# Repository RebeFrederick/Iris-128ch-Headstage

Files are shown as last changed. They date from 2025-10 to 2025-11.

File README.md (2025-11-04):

# Iris-128

Open-source 128-channel headstages for neural stimulation and recording.

*The publication of this work can be found at DOI 10.1088/1741-2552/ae1876. The raw data files corresponding to the publication can be found at https://doi.org/10.17605/OSF.IO/XS2PU.*

> [!NOTE]
> Detail documentation and user guides can be found at https://docs.openic.org/iris-128.

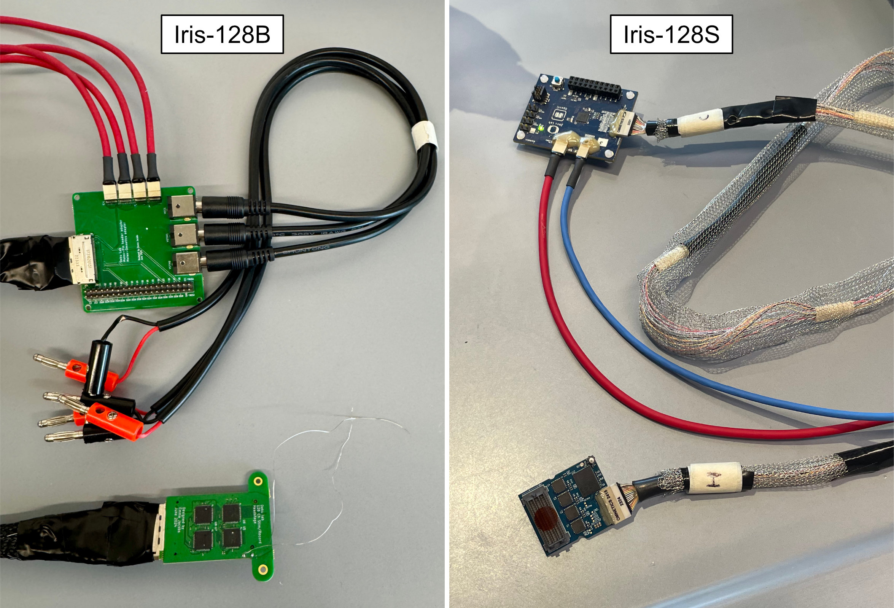
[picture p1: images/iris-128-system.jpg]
Iris-128


| Type | Description |
| :--: | :--- |
| [Iris-128B](iris-128b/README.md)  | Fully bidirectional headstage with recording or stimulation across all 128 electrode channels. |
| [Iris-128S](iris-128s/README.md) | Selective stimulation headstage with recording from 128 channels and stimulation on 16 simultaneous channels out of 32 available stimulation channels. |
| [Thin-film electrode](thin-film/README.md) | 128 channel surface array used as a test platform for the headstages. |

## File Structure

| Folder  | Description |
| :-----: | :--- |
| iris-128b | Project, design, and fabrication files related to Iris-128B Neural Interface System. |
| iris-128s | Project, design, and fabrication files related to Iris-128S Neural Interface System. |
| thin-film | Design files related to the microelectrode test platform. |
| images | image files used in README and description files. |

## EDA Tools used in the Development

| EDA Tool | Version | Usage |
| :---: | :-----: | :--- |
| KiCad | 8.0.5 | Design of PCBs. |
| KiCad | 9.0.3 | Design of PCBs. |
| STM32CubeIDE | 1.16.0  | Design of firmware for MCU. |

## Developers

* Deku Lab, University of Oregon, Eugene, OR
* OpenIC, Eagan, MN

## License

Copyright Manuel Monge, Emma Jacobs 2025.

This source describes Open Hardware and is licensed under CERN-OHL-P v2.

You may redistribute and modify this source and make products using it under the terms of the CERN-OHL-P v2 ([https:/cern.ch/cern-ohl](https:/cern.ch/cern-ohl)). This source is distributed WITHOUT ANY EXPRESS OR IMPLIED WARRANTY, INCLUDING OF MERCHANTABILITY, SATISFACTORY QUALITY AND FITNESS FOR A PARTICULAR PURPOSE. Please see the CERN-OHL-P v2 for applicable conditions.

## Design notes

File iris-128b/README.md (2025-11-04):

# Iris-128B
> [!NOTE]
> Detail documentation and user guides can be found at https://docs.openic.org/iris-128/iris-128b.

<br>

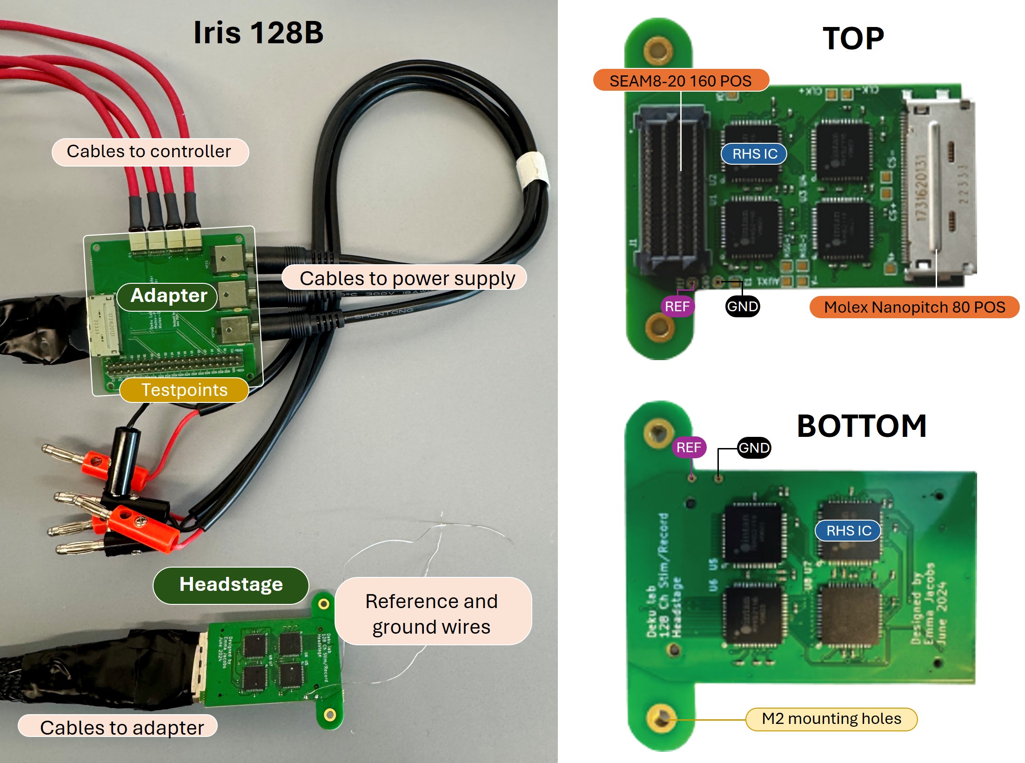
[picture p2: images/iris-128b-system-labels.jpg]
Iris-128


*Fig. 1. Iris-128B Neural Interface.*

## Description

### Overview

A **128-channel neural interface capable of stimulation and recording**.

This project develops a system that can stimulate and record from 128 channels using commercially available ICs and integrates into existing commercially available controllers (Intan RHS system). This can be used for small animal, anesthetized electrophysiology, non-human primates, or could be applied to clinical, intraoperative human use cases.

### Iris 128B Architecture

*The Iris 128B system consists of 2 boards: the headstage and the adapter.*

* The **headstage** is a small electronic system placed on top of or near the electrophysiological signals being recorded.
* It uses **commercially available off-the-shelf components**.
* The **adapter board** receives signals from the headstage (through the 80 pin nanopitch Molex connector and cable) and breaks them out into cables that interface with the **Intan Rec/Stim Controller**.

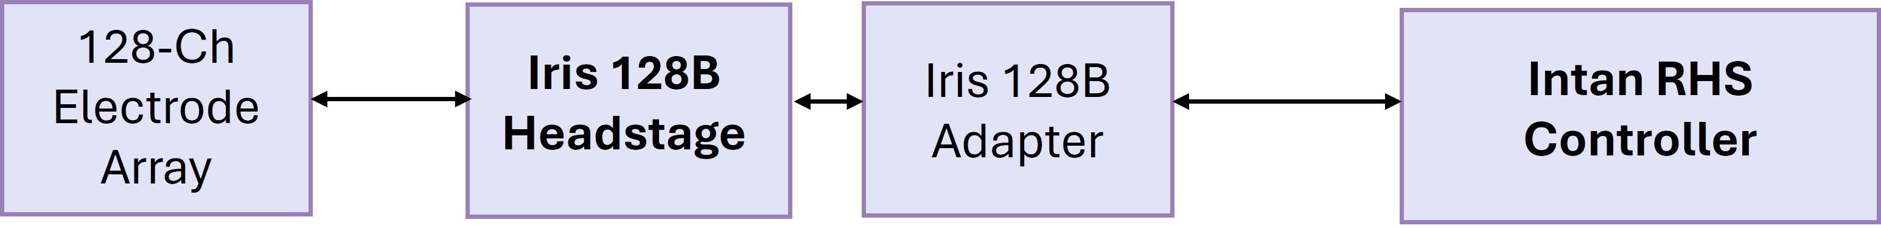
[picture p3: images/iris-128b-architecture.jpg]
Iris-128


*Fig. 2. System architecture.*

<br>

## Specifications

* Recording and stimulation from all 128 channels.
* Compatible with Intan Recording Controller and Intan Stim/Record Controller.
* *SEAM8 Samtec* connector for interfacing with 128-ch electrode array and compatible with *BlackRock Cereplex E headstages*.
* The *headstage* has a size of 27 x 44 mm$^2$.
* *Molex Nanopitch 76-POS* connector to interface with *Adapter* board through a single cable.
* *Adapter* board draws power from power supply.
* The *adapter* has a size of 57 x 58 mm$^2$.

<br>

## File Structure

### Top Folders: /iris-128b

| Folder  | Subfolders | Description |
| :-----: | :--- | :--- |
| pcb | iris-128b <br> iris-128b-adapter <br> libraries | Project, design, and fabrication files related to Iris-128B headstage PCB fabrication and assembly. <br> Project, design, and fabrication files related to Iris-128B adapter PCB fabrication and assembly. <br> Ki-Cad libraries and common files used in PCBs |

<br>

### PCB Folders: /iris-128b/pcb/

| Folder  | Subfolders | Description |
| :-----: | :--- | :--- |
| . / |  | Project and design files related to Iris128B. |
| manufacturing |  gerber <br> assembly <br> bom | Gerber files for fabrication of `Iris-PCB`. <br> Assembly files for `Iris-PCB`. <br> Bill of Materials for `Iris-PCB`. |

<br>

## File Types

| File | Folder | Description |
| :--- | :----- | :--- |
| README.md | iris-128x | Description of Iris-128X system. |
| kicad-files | iris-128x / pcb / | Ki-Cad project and design files. |
| gerber-files | iris-128x / pcb / manufacturing / gerber | Gerber files. |
| iris-128x-all-pos.csv | iris-128x / pcb / manufacturing / assembly | Assembly files in `csv` format.|
| iris-128x_bom.csv | iris-128x / pcb / manufacturing / bom | Bill of materials in `csv` format. |
| symbol-libraries | iris-128x / pcb / libraries | Ki-Cad symbol libraries used in PCBs. |
| footprint-libraries | iris-128x / pcb / libraries | Ki-Cad footprint libraries used in PCBs. |

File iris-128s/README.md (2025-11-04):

# Iris-128S
> [!NOTE]
> Detail documentation and user guides can be found at https://docs.openic.org/iris-128/iris-128s.

<br>

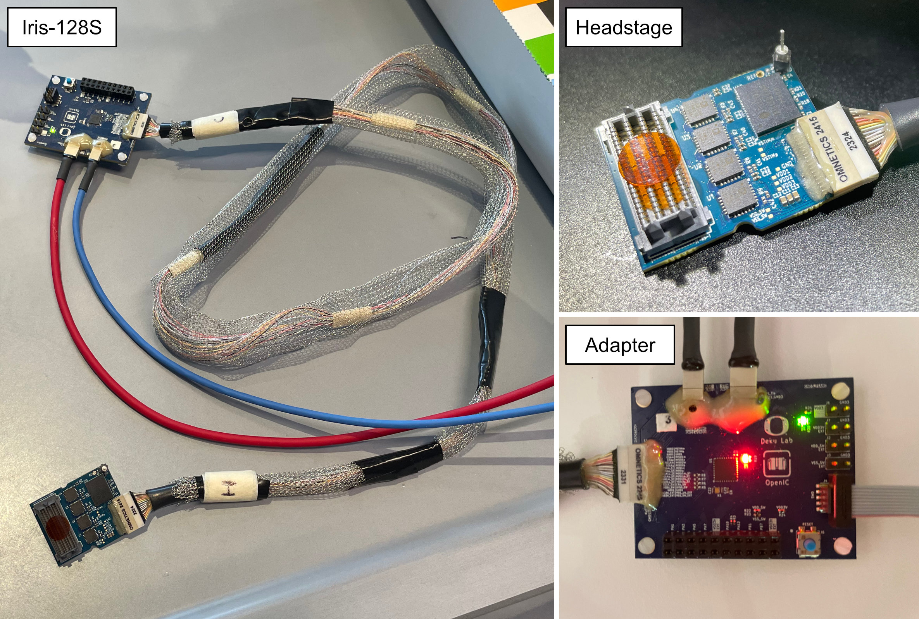
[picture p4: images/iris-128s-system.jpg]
Iris-128S System

<p style="text-align:center"><i><b>Figure 1.</b> Iris-128S Neural Interface.</i></p>

<br>

## Description

The Iris-128S neural interface consists of 2 boards: the *headstage* and the *adapter*. The *headstage* is a small electronic board that is normally placed on top of or nearby the animal model being studied. It has been designed to be as small as possible while using standard, commercially available off-the-shelf components. The *adapter* is a small electronic board which has been designed to interface with the Intan Recording Controller, the Intan Rec/Stim Controller, and a programmer/computer to program the switches in the *headstage* via a MCU.

The architecture and schematic of Iris-128S are shown in the figures below.

```mermaid
graph LR
    c0["128-Ch
        Electrode
        Array"]
    c1["`**Headstage**`"]
    c2["`**Adapter**`"]
    c3["Intan Rec
        Controller"]
    c4["Intan Rec/Stim
        Controller"]
    c5["Programmer"]
    c0 <--> c1
    c1 <----> c2
    c2 <--> c3
    c2 <--> c4
    c2 <--> c5
```
<p style="text-align:center"><i><b>Figure 2.</b> System Architecture of Iris-128S.</i></p>

<br>

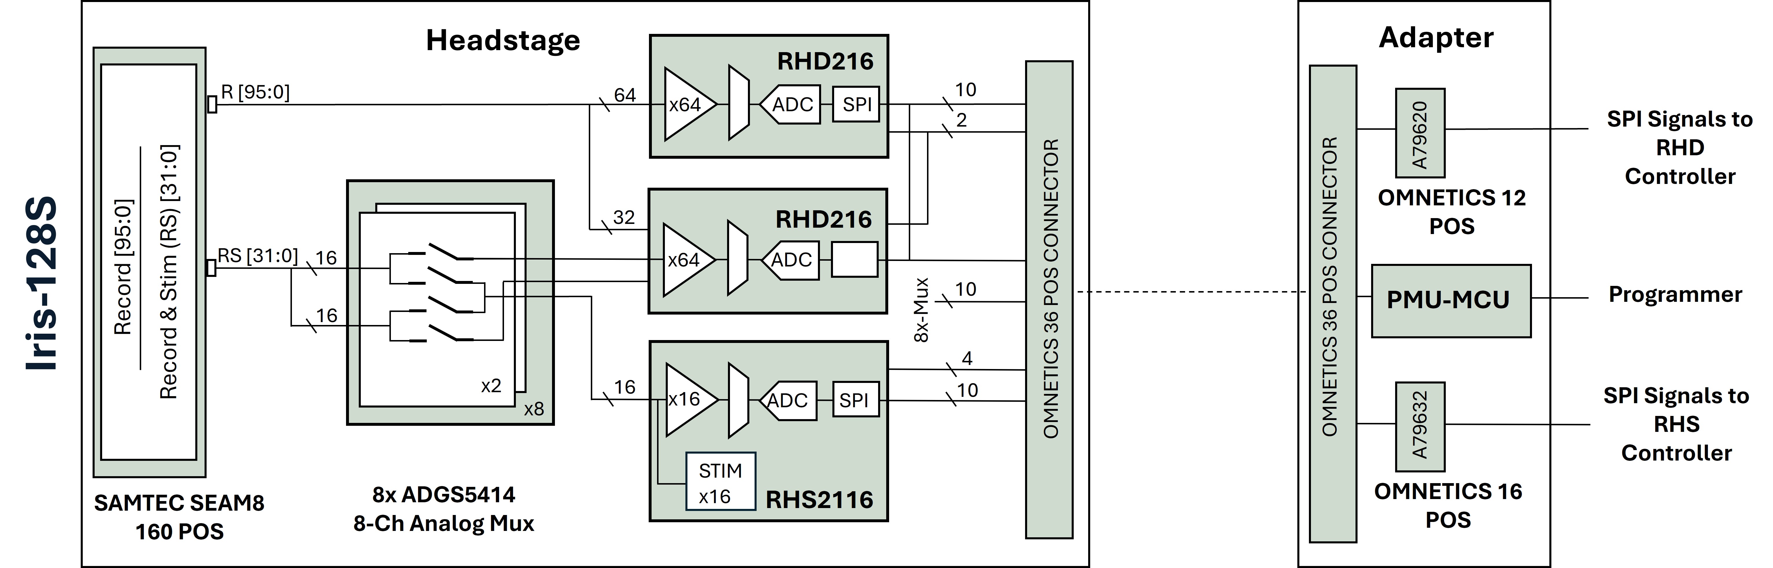
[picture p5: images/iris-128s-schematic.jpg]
Iris-128S System

<p style="text-align:center"><i><b>Figure 3.</b> Schematic of Iris-128S.</i></p>

<br>

## Specifications

* Recording from all 128 channels.
* Stimulation from 32 designated channels, where up to 16 of them can be selected for simultaneous stimulation.
* Compatible with Intan Recording Controller and Intan Stim/Record Controller.
* *SEAM8 Samtec* connector for interfacing with 128-ch electrode array and compatible with *BlackRock Cereplex E headstages*.
* The *headstage* has a size of 30.2 x 25.5 mm$^2$.
* *Omnetics 36-POS* connector to interface with *Adapter* board through a single cable.
* *Adapter* board draws power directly from the Intan Recording Controller to power itself and the *headstage*.
* On-board power management unit (PMU) in the *Adapter* board generates the required supplies for the MCU and *ADGS5414* switches.
* Programmer in the *Adapter* board is only needed to update the firmware in the MCU, i.e., change the state of the *ADGS5414* switches. After MCU is programmed, only the Intan controlleres are needed.
* The *adapter* has a size of 50 x 40 mm$^2$.

<br>

## File Structure

### Top Folders: /iris-128s

| Folder  | Subfolders | Description |
| :-----: | :--- | :--- |
| pcb | iris-128s <br> iris-128s-adapter <br> libraries <br> datasheets | Project, design, and fabrication files related to Iris-128S headstage PCB fabrication and assembly. <br> Project, design, and fabrication files related to Iris-128S adapter PCB fabrication and assembly. <br> Ki-Cad libraries and common files used in PCBs <br> Datasheets of components used in PCBs. |
| mcu | controller | Project and firmware files related to MCU programming. |

<br>

### PCB Folders: /iris-128s/pcb/`Iris-PCB`

| Folder  | Subfolders | Description |
| :-----: | :--- | :--- |
| . / |  | Project and design files related to `Iris-PCB`. |
| manufacturing |  gerber <br> assembly <br> bom | Gerber files for fabrication of `Iris-PCB`. <br> Assembly files for `Iris-PCB`. <br> Bill of Materials for `Iris-PCB`. |

<br>

### MCU Folders: /iris-128s/mcu

| Folder  | Subfolders | Description |
| :-----: | :--- | :--- |
| controller | Core / Inc <br> Core / Src <br> Core / Startup <br> Debug <br> Drivers | `C` library files. <br> `C` source files. <br> Assembly startup file. <br> Debug-related files. <br> Driver files for target MCU. |

<br>

## File Types

| File | Folder | Description |
| :--- | :----- | :--- |
| README.md | iris-128x | Description of Iris-128X system. |
| pcb-fab-specs.md | iris-128x / pcb | Specifications for the fabricatin of `Iris-PCB`.
| kicad-files | iris-128x / pcb / `Iris-PCB` | Ki-Cad project and design files. |
| iris-128x-schematic.pdf | iris-128x / pcb / `Iris-PCB` | PDF of PCB schematic. |
| gerber-files | iris-128x / pcb / `Iris-PCB` / manufacturing / gerber | Gerber files. |
| iris-128x-all-pos.csv | iris-128x / pcb / `Iris-PCB` / manufacturing / assembly | Assembly files in `csv` format. |
| iris-128x_bom.csv | iris-128x / pcb / `Iris-PCB` / manufacturing / bom | Bill of materials in `csv` format. |
| datasheet-files.pdf | iris-128x / pcb / datasheets | PDFs of the datasheets of all components used in PCBs. |
| symbol-libraries | iris-128x / pcb / libraries | Ki-Cad symbol libraries used in PCBs. |
| footprint-libraries | iris-128x / pcb / libraries | Ki-Cad footprint libraries used in PCBs. |
| main.c | iris-128s / mcu / controller / Core / Src | Main `C` file running on MCU. |
| c-files | iris-128s / mcu / controller / Core | `C` files related to MCU firmware. |
| c-files | iris-128s / mcu / controller / Debug | `C` files related to MCU debugging. |
| c-files | iris-128s / mcu / controller / Drivers | `C` file related to MCU drivers. |
| .*project | iris-128s / mcu / controller | STM32CubeIDE project-related files. |
| *.launch | iris-128s / mcu / controller | STM32CubeIDE debug-related files. |
| *.ioc | iris-128s / mcu / controller | STM32CubeIDE MCU system configuration file. |
| *.id | iris-128s / mcu / controller | STM32CubeIDE MCU memory configuration file. |

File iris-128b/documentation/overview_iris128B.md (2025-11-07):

# Iris-128B

Iris-128

*Fig. 1. Iris-128B Neural Interface.*

The left labels the cables and components needed for the system, in addition to the Intan RHS controller and electrodes. Fig. 1 shows the front of Iris 128B with a SEARAY 160 pin connector, four RHS2000 ICs, an 80-pin Molex connector, pinouts, decoupling capacitors, and terminating resistors. Mounting holes are M2. The back of Iris 128B with four RHS2000 ICs.

## Description

### Components

The descriptions of each part of the system can be found below, along with a quick start guide.

| Component | Page |
| :-----: | :----- |
| Headstage | Headstage|
| Adapter | Adapter|
| Quick start guide | Quick start guide|

### Overview

A 128-channel neural interface capable of stimulation and recording.

This project develops a system that can stimulate and record from 128 channels using commercially available ICs and integrates into existing commercially available controllers (Intan RHS system). This can be used for small animal, anesthetized electrophysiology, non-human primates, or could be applied to clinical, intraoperative human use cases.

### Iris 128B Architecture

*The Iris 128B system consists of 2 boards: the headstage and the adapter.*

* The headstage is a small electronic system placed on top of or near the electrophysiological signals being recorded.
* It uses commercially available off-the-shelf components.
* The adapter board receives signals from the headstage (through the 80 pin nanopitch Molex connector and cable) and breaks them out into cables that interface with the **Intan Rec/Stim Controller**.

Iris-128

*Fig. 2. System architecture.*

<br>

## Specifications

* Recording and stimulation from all 128 channels.
* Compatible with Intan Recording Controller and Intan Stim/Record Controller.
* *SEAM8 Samtec* connector for interfacing with 128-ch electrode array and compatible with *BlackRock Cereplex E headstages*.
* The *headstage* has a size of 27 x 44 mm$^2$.
* *Molex Nanopitch 76-POS* connector to interface with *Adapter* board through a single cable.
* *Adapter* board draws power from power supply.
* The *adapter* has a size of 57 x 58 mm$^2$.

<br>

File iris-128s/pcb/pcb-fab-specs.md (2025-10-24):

# Iris-128S PCB Specifications

The table below shows the specifications for the Iris-128S PCBs.

| Specification | Headstage | Adapter |
| :---: | :---: | :---: |
| Min. Trace Width/Space | 3 mil / 3 mil  | 5 mil / 5 mil |
| # Layers | 8 | 4 |
| $\mu$Via (Hole/Diameter) | 6 mil / 12 mil | None |
| Thru-Hole Via (Hole/Diameter) | 8 mil / 14 mil | 10 mil / 20 mil |
| Board Thickness | 1 mm | 1.6 mm |
| Surface Finish | ENIG | ENIG |
| Copper Weight | 1 oz | 1 oz |
| Dielectric | Standard FR4 | Standard FR4 |

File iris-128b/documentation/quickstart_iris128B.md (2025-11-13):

# Iris-128B Quickstart Guide
*Open-Source 128-Channel Headstage for Neural Recording and Stimulation*  
*(Based on Jacobs et al., 2025 – “Iris 128x: Open-Source 128-Channel Headstages for Neural Stimulation and Recording”)*  

---

## 1. System Overview

The Iris-128B system provides 128-channel, fully bidirectional recording and stimulation capability using eight Intan RHS2116 integrated amplifier/stimulator chips.  
It interfaces with thin-film microelectrode arrays through a Samtec SEAF8-20-1-S-08-2-RA connector and communicates with an Intan RHS Controller via low-voltage differential signaling (LVDS) through a Molex 80-pin nanopitch cable and an adapter board.

---

## 2. Power Supply Requirements

Use a bench DC power supply such as the HP E3631A Triple Output DC Power Supply (HP Inc., Palo Alto, CA).  

| Rail | Voltage | Current Limit | Description |
|---|---|---|---|
| **Vstim +** | +7 V | 100 mA | Positive stimulation rail |
| **Vstim –** | –7 V | 100 mA | Negative stimulation rail |
| **VCC** | +3.3 V | 100 mA | Digital logic & analog power |

> **Tip:** Keep each supply current-limited to 100 mA to protect the headstage.

iris-128

*Fig. 1. Wiring diagram containing power supplies, intan controller, adapter board, and cable to headstage.*

---

## 3. Hardware Components

- **Headstage (Iris-128B)**  
  - 8 × Intan RHS2116 ICs (recording + stimulation)  
  - Samtec SEAF8 connector (160-pin) for thin-film MEA  
  - Molex 80-pin nanopitch output to adapter  
  - ±3.3 – 7 V supply range  

- **Adapter Board**  
  - Passive signal routing (no active components)  
  - 4 × Omnetics A79633 connectors to Intan RHS ports A–D  
  - 3 × barrel jacks for ±Vstim and VCC  

iris-128

*Fig. 2. Components and connections of headstage and adapter board.*

---

## 4. Hardware Setup

### Step 1 — Prepare for Surgery

1. Secure the animal in a stereotaxic frame.  
2. Mount the 3D-printed headstage holder onto the stereotax.  
3. Seat the thin-film electrode connector into the holder.  
4. Plug the Iris-128B headstage into the thin-film connector.  
5. Fasten the headstage to the holder via mounting holes.

iris-128

*Fig. 3. (A) Headstage with thinfilm attached to stereotax in 3d printed fixture. (B) Headstage and thinfilm.*

---

### Step 2 — Connect to Adapter

1. Connect the Molex 80-pin cable between headstage and adapter.  
2. Route this cable outside the Faraday cage.  
3. Plug in the 4 RHS interface cables (red Omnetics):  
   - **S1 → Port A** (shared CLK and CS)  
   - **S2 → Port B**  
   - **S3 → Port C**  
   - **S4 → Port D**

---

### Step 3 — Ground and Reference

- Connect REF and GND pads using platinum wires soldered into the through-holes on the headstage.  
- Keep REF and GND unshorted during normal operation.  
- Optionally, these may be tied together or implemented on the thin-film array.  
- Ensure the entire setup (animal, cage, supplies) shares a common ground.

---

## 5. Software Setup

1. Install Intan RHS Recording Controller Software (see [Intan User Guide](https://intantech.com)).  
2. Connect the RHS Controller to the computer via USB.    

---

## 6. Power-Up Sequence

1. Confirm the Intan controller and power supplies are connected to the chassis ground on the controller (green plug on back of controller) and the grounds on the power supply are all connected to each other as well.  
2. Set voltages on the HP E3631A:  
   - +7 V, –7 V, +3.3 V rails  
   - 100 mA current limits  
3. Plug barrel jacks into Vstim± and VCC inputs on the adapter.  
4. Turn on the power supply. 
5. Turn on the Intan Controller.
6. Launch the software — channels from Ports A–D should automatically appear.  
7. Adjust sampling rate and channel naming as needed.

iris-128

*Fig. 4. Software launch with 4 connected ports (total 128 channels).*

---

## 7. Bench & Animal Setup Checklist

| Stage | Procedure |
|---|---|
| **Bench Validation** | Connect planar 128-ch polyimide MEA → verify impedance in PBS (~295 kΩ @ 1 kHz). |
| **Grounding** | Attach platinum wires for REF and GND to headstage pads. |
| **Recording** | Launch Intan software → set sampling rate 30 kSa/s → confirm signal. |
| **In Vivo Setup** | Craniotomy → insert MEA into cortex → connect headstage. |
| **Validation** | Observe LFPs (0.5–100 Hz) and single-unit spikes (~250–500 µVpp). |

---

## 8. Performance Summary

| Metric | Iris 128B | Comparison (Intan 32 ch) |
|---|---|---|
| Noise (Vrms) | 3.09 µV | 2.4 µV |
| Weight | 9.6 g | 1.4 g |
| Volume | 1188 mm³ | 576 mm³ |
| Channels | 128 stim / 128 record | 32 stim / 32 record |
| Frequency Response | 0.5 Hz – 5 kHz (flat midband gain) | Similar |
| Impedance (1 kHz, Pt site) | ~2.9 × 10⁵ Ω | 2.4 × 10⁵ Ω |
| Supply | ±7 V & 3.3 V | 3.3 V (single) |

---

## 9. Stimulation Parameters

- **Chip:** Intan RHS2116 (D5716)  
- **Current Range:** 2.55 µA – 255 µA  
- **Step Size:** 10 nA – 10 µA  
- **Supply Range:** ±3.3 – 10.7 V (max combined 14 V)  
- **Sampling Rates:** 1 – 30 kS/s  
- **Test Waveform:** Biphasic cathodic-first 4 µA, 500 µs pulses, 100 Hz (0.1 mC/cm² charge density)

---

## 10. Additional Notes

- The Molex #205058-1002 cable assembly is discontinued; contact  
  **fdeku@uoregon.edu** or **manuel@openic.org** for updated options.  
- The design files, schematics, and BOMs are open-source on GitHub (OpenIC / U Oregon).  
- The Iris 128B and 128S share identical PCB stack-up and fabrication parameters:  
  – 8-layer (3 mil trace / space, ENIG finish, 1 oz Cu).  
- Designed in KiCad*, verified by micro-CT imaging and in vivo electrophysiology recordings.  
- For portable or wireless operation, future iterations aim to reduce weight < 5 g and integrate on-board power management.

---

## 11. Reference Setup Recipe

1. Power on HP E3631A (±7 V & 3.3 V outputs).  
2. Connect thin-film → headstage → adapter → Intan Controller.  
3. Verify REF/GND connections (platinum wire → bone screws).  
4. Enable power and confirm communication in Intan software.  
5. Begin recording and stimulation tests.

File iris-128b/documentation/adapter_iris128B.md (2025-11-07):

# Adapter

iris-128

*Fig. 1. Adapter connections.*

*The Iris 128B system consists of 2 boards: the headstage and the adapter.*

* The adapter board receives signals from the headstage (through the 80 pin nanopitch Molex connector and cable) and breaks them out into cables that interface with the Intan Rec/Stim Controller.

This is a board with no active components on it. It's purpose is simply to route the connections from the Iris-128B headstage to the power supply, and the four ports on the Intan RHS controller. It also has some header pins intended for testing the SPI connections.

---

### Specifications

This is a 4 layer board that only routes digital signals. It takes the signals from the headstages and breaks them out into the appropriate connector for the RHS intan controller (interfacing with PZN 18 pin omnetics cables).

iris-128

*Fig. 2. Omnetics output from adapter board. This is repeated 4 times. Each connector routes two chips into the ports on each controller.*

#### Table 1. PCB Specifications

| PCB Specification | Value |
| --- | --- |
| Size | 27 × 44 mm² |
| Trace Width / Space | 3 mil / 3 mil |
| Layers | 8 |
| Thru-Hole Via (Hole / Diameter) | 8 mil / 14 mil  |
| Microvia (Hole / Diameter) | 6 mil / 12 mil  |
| Thickness | 0.039 in (1 mm) |
| Surface Finish | ENIG |
| Copper Weight | 1 oz |

#### Table 2. Adapter components

| Component | Part | Manufacturer | Description |
| --- | --- | --- | --- |
| J1 | SEAM8-20-S02.0-S-08-3 | Samtec | 160-pin connector to electrode sites. |
| S1-S4 | Omnetics A79633 PZN-16-AA| Intan | Intan |Connector for RHS2000 interface (chip side) to the Intan controller |  
| VSTIM-, VSTIM+, VCC | CP-063AH-ND  Pwr Jack| Molex | Barrel jack inputs for the power supplies. |

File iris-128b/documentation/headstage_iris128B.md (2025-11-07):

# Headstage

Iris-128
*Fig. 1. Schematic of Iris 128B.*

*The Iris 128B system consists of 2 boards: the headstage and the adapter.*

* The headstage is a small electronic system placed on top of or near the electrophysiological signals being recorded.
* It uses commercially available off-the-shelf components.

### Fabrication Notes

The cable used to connect the headstage to the adapter board is Molex 8X STR NPIO/ 8X STR NPIO 2PC LATCH 34A, #205058-1002. This cable is no longer manufactured. However, the connector is still available. We are working on alternatives - and a smaller version of these headstages. Feel free to contact us (fdeku@uoregon.edu or manuel@openic.org) if you would like to use this design and want to discuss alternative options. 

If you are able to use the Molex nanopitch cables, please note:

* In this design, pins *Chip 5 – MOSI+* and *Chip 5 – MOSI–* connect to unused pins on the cable (A20 and A21). To address this we modified the cable by adding wires to it after it was ordered.

#### Headstage Cost Breakdown

- 8 × $392 — RHS2116 chips  
- 1 × $24 — SEAM8-20-S02.0-S-08-3 connector  
- 1 × $67 — NPIO / 8X STR NPIO 2PC LATCH 34A cable **_(DISCONTINUED AS OF AUG. 2025)_**  
- 1 × $11 — CONN NANO-PITCH I/O RCPT 80P RA connector  
- $125 — 1 headstage printed circuit board  
- $60 — 1 adapter printed circuit board  
- 4 × $265 — RHS interface cables  

----

#### **Estimated Total Costs**
- **≈ $3,356** — Headstage  
- **≈ $1,325** — Cabling

### Components

| Component | Part | Manufacturer | Description |
| --- | --- | --- | --- |
| J1 | SEAM8-20-S02.0-S-08-3 | Samtec | 160-pin connector to electrode sites. |
| U1–U8 | RHS2116 | Intan | Stimulation & recording chip.  |
| J2 | CONN NANO-PITCH I/O RCPT 80P RA, #1731620131 | Molex | 80-pin connector that routes the digital signals from the headstage to the adapter board.  |

## Specifications

### Electrode128

*This is the output/input that interfaces with the electrophysiological signals.*

We are currently using the SEAM8 Samtec connector for interfacing with a 128-ch electrode array.
The footprint on the headstage is shown below.

The left and right two rows are dedicated for GND and REF connectors.
The remaining 16×8 are for connecting to the 128 electrodes. All the GND for the chips, power supplies, and thin-film are shared.

This is the same footprint/connector used with BlackRock Cereplex E headstages, maintaining compatibility with interchangeable thin-film interfaces.

Iris-128

*Fig. 2. Footprint of SEAM 160 (8x20) pin connector. Outer two rows are reserved for reference and gnd. The 3.3V and LED are unconnected. The locations of these gnd and reference pins are meant to match the Cereplex E headstages. We have used thin-films interchangeably between the two systems so we have preserved that footprint in this version of the headstage. The footprint is labeled C#, indicating the chip it routes to, and E# indicating the electrode.*

### Chip1 through Chip8

These are RHS2116 chips (QFN package) from Intan Technologies.
There are 8 total chips (16 electrodes each) communicating with the controller via SPI (Serial Peripheral Interface). 

Iris-128

*Fig. 2. Footprint of RHS2116 on Iris128B with broadly labeled pins. See the Intan RHS2116 datasheet for specific details. *

The reference and ground pins can be shorted or disconnected using the pads shown below.

Iris-128

*Fig. 3. Footprint location of pads to short ref and gnd. Also seen here are the plated through holes on the left where gnd and ref wires can be soldered.*

Digital (SPI) communication lines to each of the 8 chips:

* Chip Select (CS)
* Serial Clock (SCLK)
* Serial Data Input (MOSI)
* Serial Data Output (MISO)

Because **LVDS (Low-Voltage Differential Signaling)** is used to decrease noise sensitivity, each line type has a + and – pair:

* CS+, CS–
* SCLK+, SCLK–
* MOSI+, MOSI–
* MISO+, MISO–

LVDS transmits low-voltage paired differential signals, reducing electromagnetic interference (EMI).

**Power requirements:**

* ±3.3V to ±7V for stimulation
* 3.3V for digital logic and analog power
* ~50 mW consumption (RHS2116, 16 channels recording)

For comparison:

* **RHD2164**: 3.3V single supply, no stimulation, ~75 mW for 64 channels.

Iris-128

*Fig. 4. Footprint of Molex 80 pin connector on Iris128B with broadly labeled pins. Any unlabled pins are digital communication lines to the chips. Not the x for NC pins due to the commericially available cable assembly.*

SPI lines are routed through the adapter board to the Intan RHS controller ports A–D.
SCLK and CS lines are shared between all chips, while data input/output lines are individually connected.

### Layers

#### Table 1. PCB Specifications

| PCB Specification | Value |
| --- | --- |
| Size | 27 × 44 mm² |
| Trace Width / Space | 3 mil / 3 mil |
| Layers | 8 |
| Thru-Hole Via (Hole / Diameter) | 8 mil / 14 mil  |
| Microvia (Hole / Diameter) | 6 mil / 12 mil  |
| Thickness | 0.039 in (1 mm) |
| Surface Finish | ENIG |
| Copper Weight | 1 oz |

Iris-128

#### Table 5. Headstage PCB Stack Up

| Layer | Notes |
| ----- | --- |
| 1 | Minimal local routing + GND plane |
| | *Prepreg* |
| 2 | Supplies + SPI + some electrode signal routing + GND plane |
| | *Core* |
| 3 | GND plane |
| | *Prepreg* |
| 4 | Signal routing + some supply traces + GND plane |
| | *Core* |
| 5 | Signal routing + GND plane |
| | *Prepreg* |
| 6 | Signal routing + GND plane |
| | *Core* |
| 7 | GND plane + SPI routing |
| | *Prepreg* |
| 8 | Minimal local routing + GND plane |

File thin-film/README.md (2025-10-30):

# Thin-film

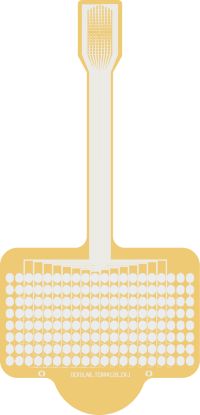
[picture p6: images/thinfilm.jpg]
Thin-film


*Fig. 1. Thinfilm used as test platform for headstages.*

## Description

`THINFILM`.

### Overview

A **Thinfilm**.

This is the design for the 128 microelectrode array fabricated by the Deku lab to test the Iris 128B and S headstages.

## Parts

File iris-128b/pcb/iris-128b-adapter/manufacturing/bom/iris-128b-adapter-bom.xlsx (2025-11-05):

Item # | *Designator | *Qty | Manufacturer | *Mfg Part # | Description / Value | *Package/Footprint | Mounting Type
1 | J1 | 1 | Digikey | WM24876TR-ND - Tape & Reel (TR) | CONN NANO-PITCH I/O RCPT 80P RA | SMD | SMD
2 | C3, C2, C1 | 3 | Mouser | 963-TMK063B7103KP-F | Multilayer Ceramic Capacitors MLCC - SMD/SMT 963-MSAST063SB7103KF RPLCMT PN 25V 0.01uF X7R 0201 10% | SMD | SMD
3 | J2 | 1 | Mouser | 571-7-146256-0 | Headers & Wire Housings 40P HEADER GOLD 15u double row | Thru-hole | Thru-hole
4 | VSTIM-, VSTIM+, VCC | 3 | Digikey | CP-063AH-ND | CONN PWR JACK 2X5.5MM SOLDER | Thru-hole | Thru-hole
5 | S1, S2, S3, S5 | 4 |  |  | POLARIZED NANO CONNECTOR | SMD | SMD
6 | R1, R2, R3, R4, R5, R6 | 6 | Digikey | CRCW0201100RFNED | RES SMD 100 OHM 1% 1/20W 0201 | SMD | SMD

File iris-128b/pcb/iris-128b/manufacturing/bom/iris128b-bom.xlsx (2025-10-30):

Item # | *Designator | *Qty | *Mfg Part # | Description / Value | Vendor Part # | *Package/Footprint | Mounting Type
1 | J1 | 1 | SEAM8-20-S02.0-S-08-3 | CONN HD ARRAY PLUG 0.8MM 8X20POS | Samtec Inc.『 』SEAM8-20-S02.0-S-08-3 | SMD | SMD
2 | C1-C24 | 24 |  | CAP CER 0.1UF 10V X5R 0201 | Digikey『 』3372-0201W104K100LETR-ND | SMD | SMD
3 | U1, U2, U3, U4, U5, U6, U7, U8 | 8 |  | Intan RHS 2000 | Intan | QFN | SMD
4 | R10, R11, R2, R3, R4, R5, R6, R7, R8, R9 | 4 | RC0201FR-07100RL | RES 100 OHM 1% 1/20W 0201 | Digikey『 』311-100MTR-ND | SMD | SMD
5 | LVDS1, LVDS3, LVDS2, LVDS4, LVDS5, LVDS8, LVDS7, LVDS6, R1 | 13 | RMCF0201ZT0R00 | RES 0 OHM JUMPER 1/20W 0201 | Digikey『 』RMCF0201ZT0R00TR-ND | SMD | SMD
6 | C25-32 | 8 | TMK063B7103KP-F | Multilayer Ceramic Capacitors MLCC - SMD/SMT 963-MSAST063SB7103KF RPLCMT PN 25V 0.01uF X7R 0201 10% | Mouser『 』963-TMK063B7103KP-F | SMD | SMD
7 | J2 | 1 | 1731620131 | CONN NANO-PITCH I/O RCPT 80P RA | Digikey『 』WM24876TR-ND - Tape & Reel (TR) | SMD | SMD

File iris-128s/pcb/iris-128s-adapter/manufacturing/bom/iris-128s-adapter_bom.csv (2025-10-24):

Reference | Value | Qty | DNP | MPN | Manufacturer | Description
C1 | 4.7u | 1 |  | KGM05CR51C475MH | Kyocera AVX | Unpolarized capacitor
C2,C9,C11,C16,C18,C19 | 1u | 6 |  | GRM033R61C105ME15D | Murata Electronics | Unpolarized capacitor
C3,C4,C6,C24 | 100n | 4 |  | C0603X5R1C104K030BC | TDK | Unpolarized capacitor
C5 | 10n | 1 |  | GRM033R61C103KA12D | Murata Electronics | Unpolarized capacitor
C7,C12,C13 | 10u | 3 |  | GRM188R61E106KA73D | Murata Electronics | Unpolarized capacitor
C8,C10 | 33n | 2 |  | GRM033R61C333KE84D | Murata Electronics | Unpolarized capacitor
C14,C15,C20,C21 | 2.2u | 4 |  | GRM035R61C225ME01D | Murata Electronics | Unpolarized capacitor
C17 | 1n | 1 |  | GRM033R61E102KA01J | Murata Electronics | Unpolarized capacitor
C22,C23 | 2p | 2 |  | GJM0335C1E2R0WB01D | Murata Electronics | Unpolarized capacitor
D1,D2 | ~ | 2 |  | SDM05U20CSP-7 | Diodes Incorporated
D3 | ~ | 1 |  | CSL1901UW1 | ROHM | LED-RED-0603-ROHM-CSL1901UW1
D4 | ~ | 1 |  | LGQ396 | OSRAM | LED-GREEN-0603-OSRAM-LGQ396
J1,J2,J3,J7 | ~ | 4 |  | TLW-102-06-G-S | Samtec | Header-Low-Profile-Male-2_2x1_P0.1in
J4 | ~ | 1 |  | FTSH-105-01-L-DV-K | Samtec | ARM10-10_2x5_P0.05in
J5 | ~ | 1 |  | SLW-110-01-G-D | Samtec | Header-Low-Profile-Female-20_2x10_P0.1in
J6 | ~ | 1 |  | 7914G-1-000 | Bournes | PUSHBUTTON-7914G-1-000
L1 | 3.3u | 1 |  | XFL2006-332MEC | Coilcraft
L2 | 4.7u | 1 |  | XFL2006-472MEC | Coilcraft
R1 | 0 | 1 |  | RC0201FR-070RL | Yageo | Resistor
R3,R4 | 4.7k | 2 |  | RC0201FR-074K7L | Yageo | Resistor
R5,R6,R7,R8,R21,R22,R23,R24 | 0 | 8 |  | RC0402JR-070RL | Yageo | Resistor
R9 | 4.87k | 1 |  | RC0201FR-074K87L | Yageo | Resistor
R10 | 7.5k | 1 |  | RC0201FR-077K5L | Yageo | Resistor
R11 | 1.15M | 1 |  | CRCW02011M15FNED | Vishay Dale | Resistor
R12,R13 | 100k | 2 |  | RC0201FR-07100KL | Yageo | Resistor
R14 | 1.33M | 1 |  | CRCW02011M33FNED | Vishay Dale | Resistor
R15 | 8.06k | 1 |  | RC0201FR-078K06L | Yageo | Resistor
R16,R18 | 10k | 2 |  | RC0201FR-0710KL | Yageo | Resistor
R17 | 64.9k | 1 |  | RC0201FR-0764K9L | Yageo | Resistor
R19 | 402 | 1 |  | RCS0402402RFKED | Vishay Dale | Resistor
R20 | 499 | 1 |  | RCS0402499RFKED | Vishay Dale | Resistor
S1 | ~ | 1 |  | A79623-001 | Omnetics | 12-pin Omnetics connector for RHD2000-Cable-Amp-Side
S2,S3,S6,S7 | ~ | 4 |  | None | None | MOUNTING_HOLE-PAD-0.1IN
S4 | ~ | 1 |  | A79633-001 | Omnetics | 16-pin Omnetics Connector for RHD2000
S5 | ~ | 1 |  | A79024-001 | Omnetics | 36-pin Omnetics Connector
U1 | ~ | 1 |  | STM32U083KCU6 | ST Microelectronics | STM32 Ultra-low-power Arm M0+, 32-bit MCU
U2 | ~ | 1 |  | ADP5070ACPZ-R7 | Analog Devices | DC-to-DC Switching Regulator with Independent Positive and Negative Outputs
U3 | ~ | 1 |  | ADP7142ACPZN5.0-R7 | Analog Devices | 40 V, 200 mA, Low Noise, CMOS LDO Linear Regulator
U4 | ~ | 1 |  | ADP7182ACPZN-R7 | Analog Devices | –28 V, −200 mA, Low Noise, Linear Regulator
U5 | ~ | 1 |  | TLV7113030DDSER | Texas Instruments | Dual, 200mA, Low-IQ Low-Dropout Regulator for Portable Devices
X1 | ~ | 1 |  | ECS-.327-6-1210B-N-TR | ECS | CRYSTAL-ECS-ECX-1210B-32KHZ

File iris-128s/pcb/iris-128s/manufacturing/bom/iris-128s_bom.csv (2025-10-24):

Reference | Value | Qty | DNP | MPN | Manufacturer
C1,C2,C4,C5,C7,C9,C10,C32,C33,C34,C35,C36,C37,C38,C39,C40,C41,C42,C43,C44,C45,C46,C47 | 100n | 23 |  | C0603X5R1C104K030BC | TDK
C3,C6,C8 | 10n | 3 |  | GRM033R61C103KA12D | Murata Electronics
C11,C12,C13 | 4.7u | 3 |  | KGM05CR51C475MH | Kyocera AVX
GND1,REF0,TP1,TP2,TP3,TP4,TP5,TP6,TP7,TP8 | -- mixed values -- | 10 |  | ~
R2,R3,R4,R5,R6,R7,R8,R9 | 20k | 8 |  | RC0201FR-0720KL | Yageo
R10,R14,R19 | 0 | 3 | DNP
R11,R39 | 1 | 2 |  | RC0201FR-071RL | Yageo
R12,R13,R15,R16,R18,R20,R21 | 100 | 7 |  | RC0201FR-07100RL | Yageo
S3 | ~ | 1 |  | A79024-001 | Omnetics
S5 | ~ | 1 |  | SEAM8-20-S02.0-S-08-3 | Samtec
U1,U2,U3,U4,U5,U6,U7,U8 | ~ | 8 |  | ADGS5414BCPZ | ADI
U9,U10 | ~ | 2 |  | RHD2164 | Intan Technologies
U12 | ~ | 1 |  | RHS2116 | Intan Technologies

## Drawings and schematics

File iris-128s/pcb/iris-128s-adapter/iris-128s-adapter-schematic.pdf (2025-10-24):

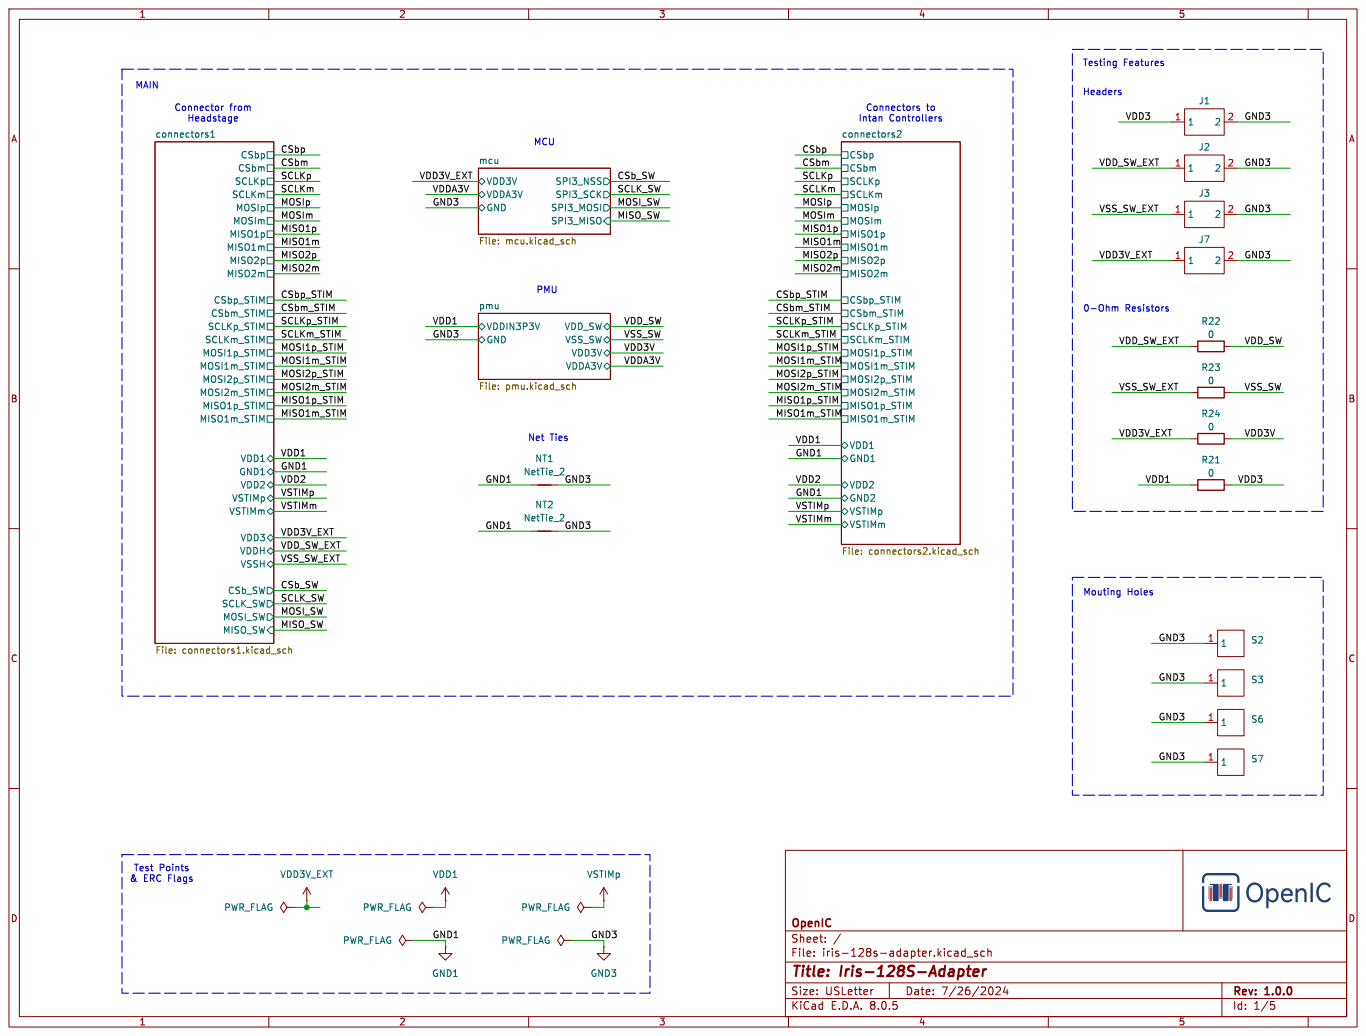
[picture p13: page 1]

Test Points & ERC Flags

Id: 1/5 Title: Iris-128S-Adapter File: iris-128s-adapter.kicad_sch Sheet: / OpenIC

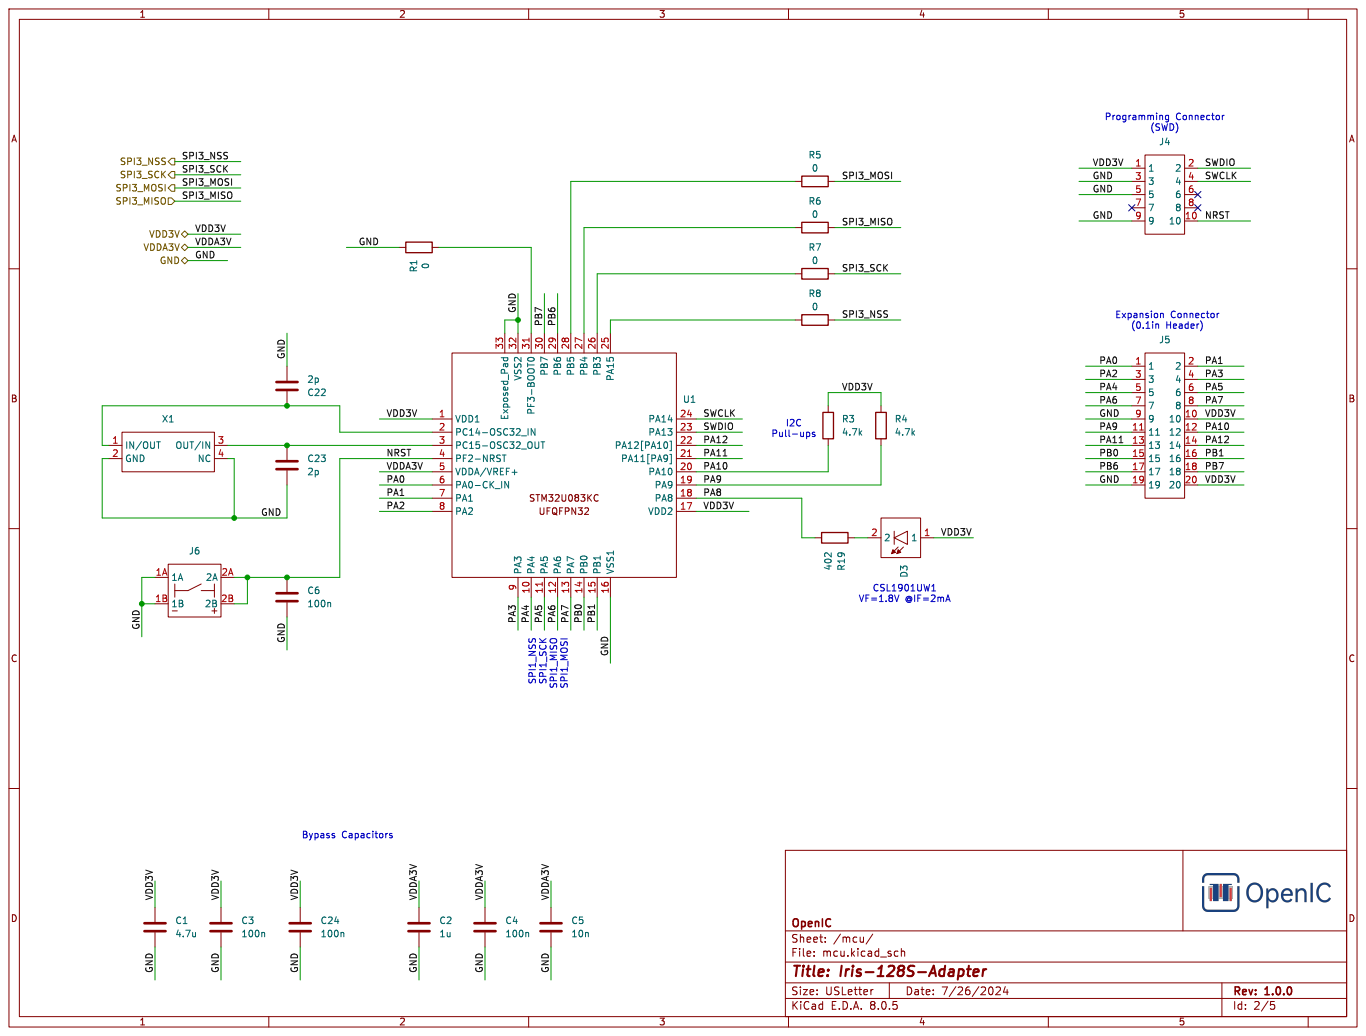
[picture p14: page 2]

SWCLK NRST PA7 PA4 PA9 VDD3V GND GND

Id: 2/5 Title: Iris-128S-Adapter File: mcu.kicad_sch Sheet: /mcu/ OpenIC

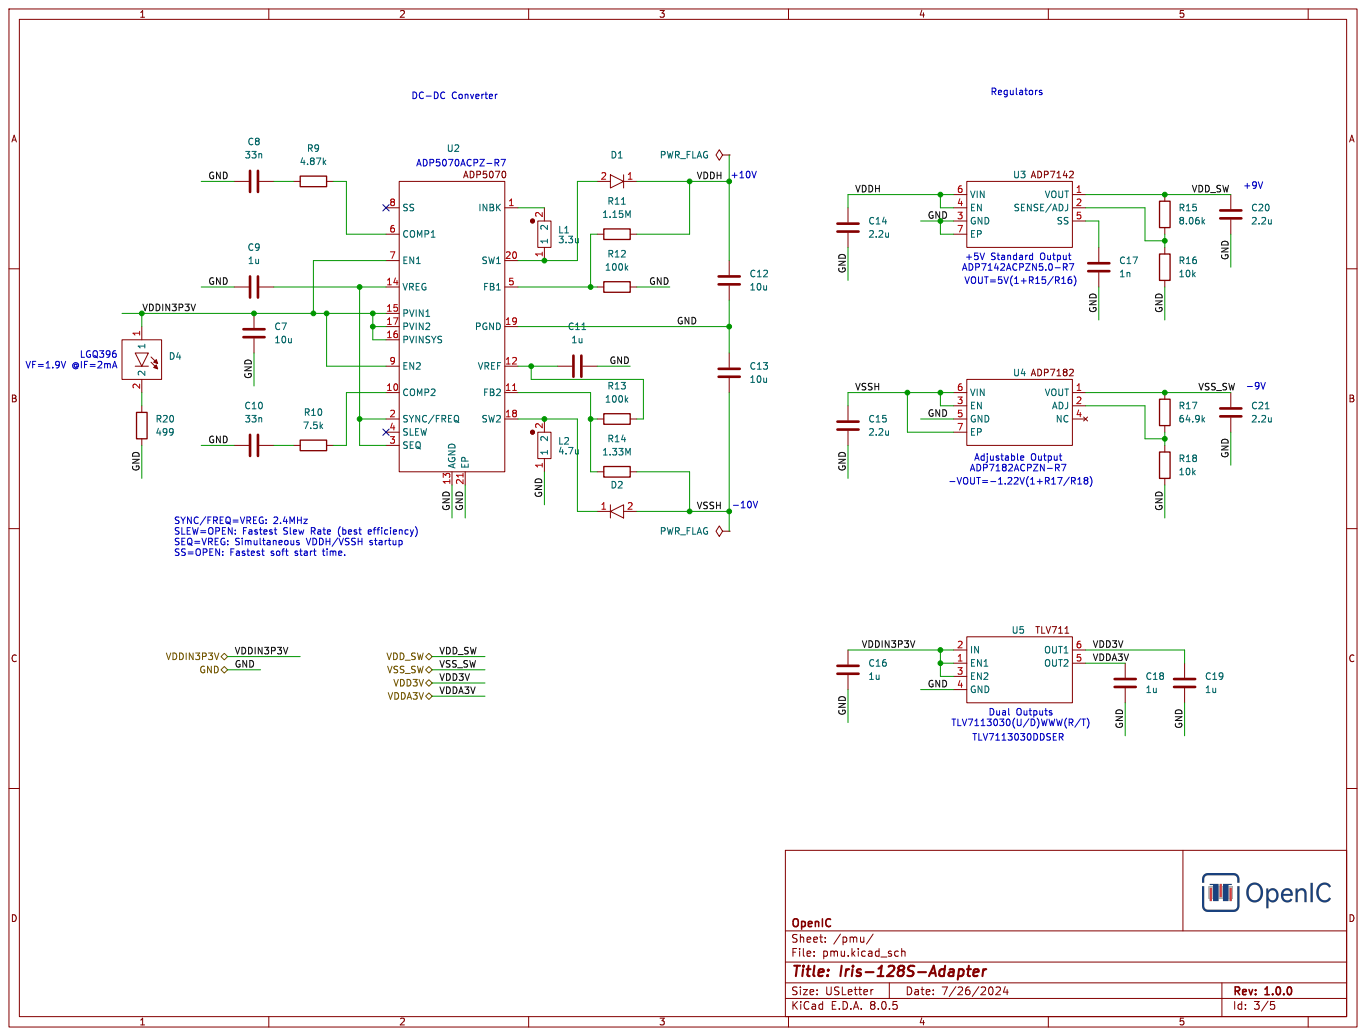
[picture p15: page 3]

E.D.A. 8.0.5 Size: USLetter Rev: 1.0.0 Id: 3/5 Title: Iris-128S-Adapter File: pmu.kicad_sch Sheet: /pmu/ | D Date: 7/26/2024 KiCad
OpenIC

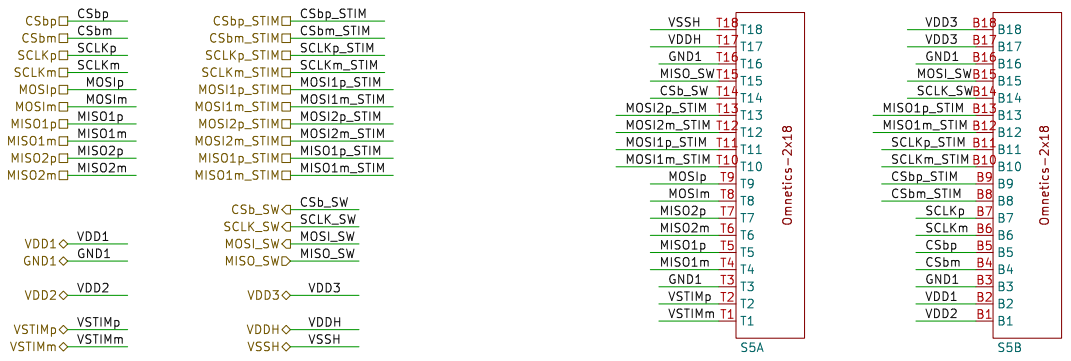
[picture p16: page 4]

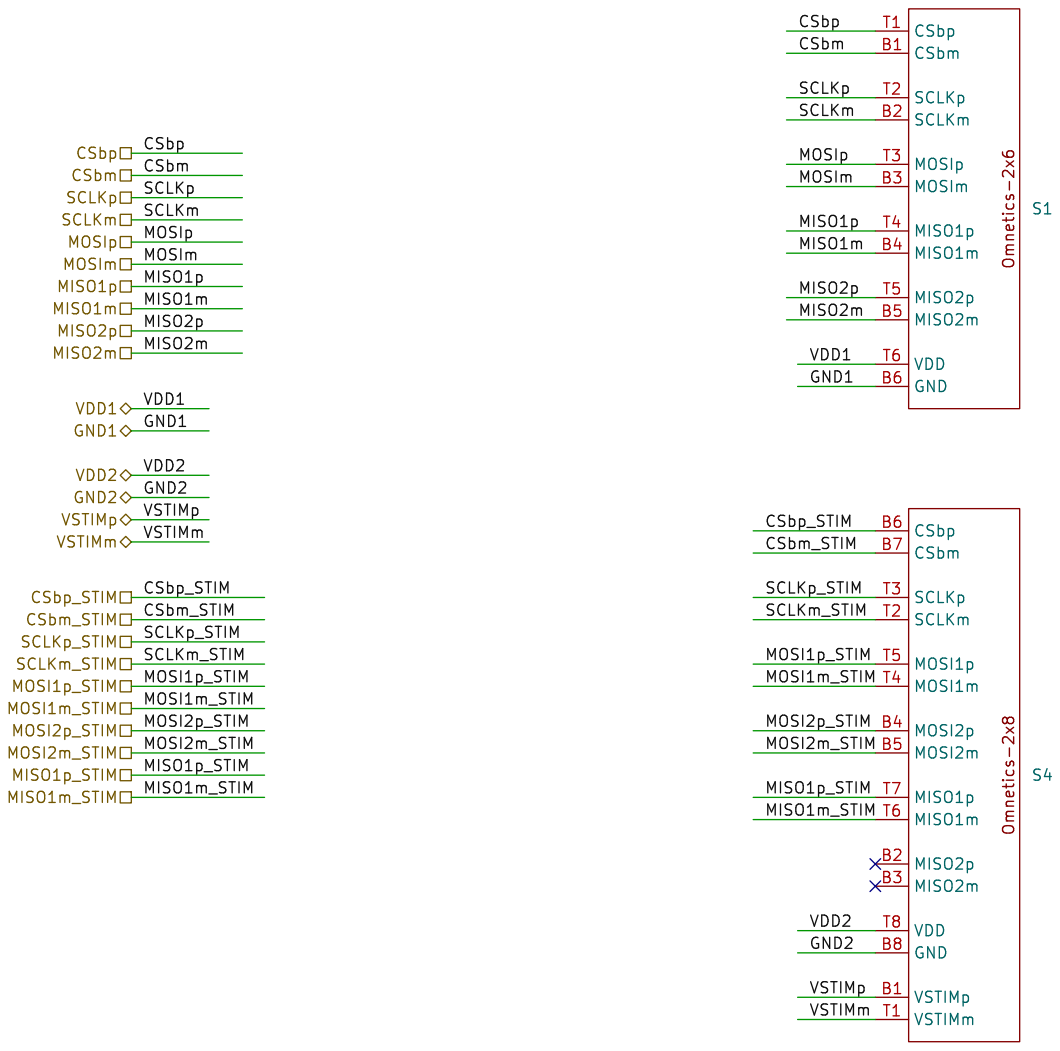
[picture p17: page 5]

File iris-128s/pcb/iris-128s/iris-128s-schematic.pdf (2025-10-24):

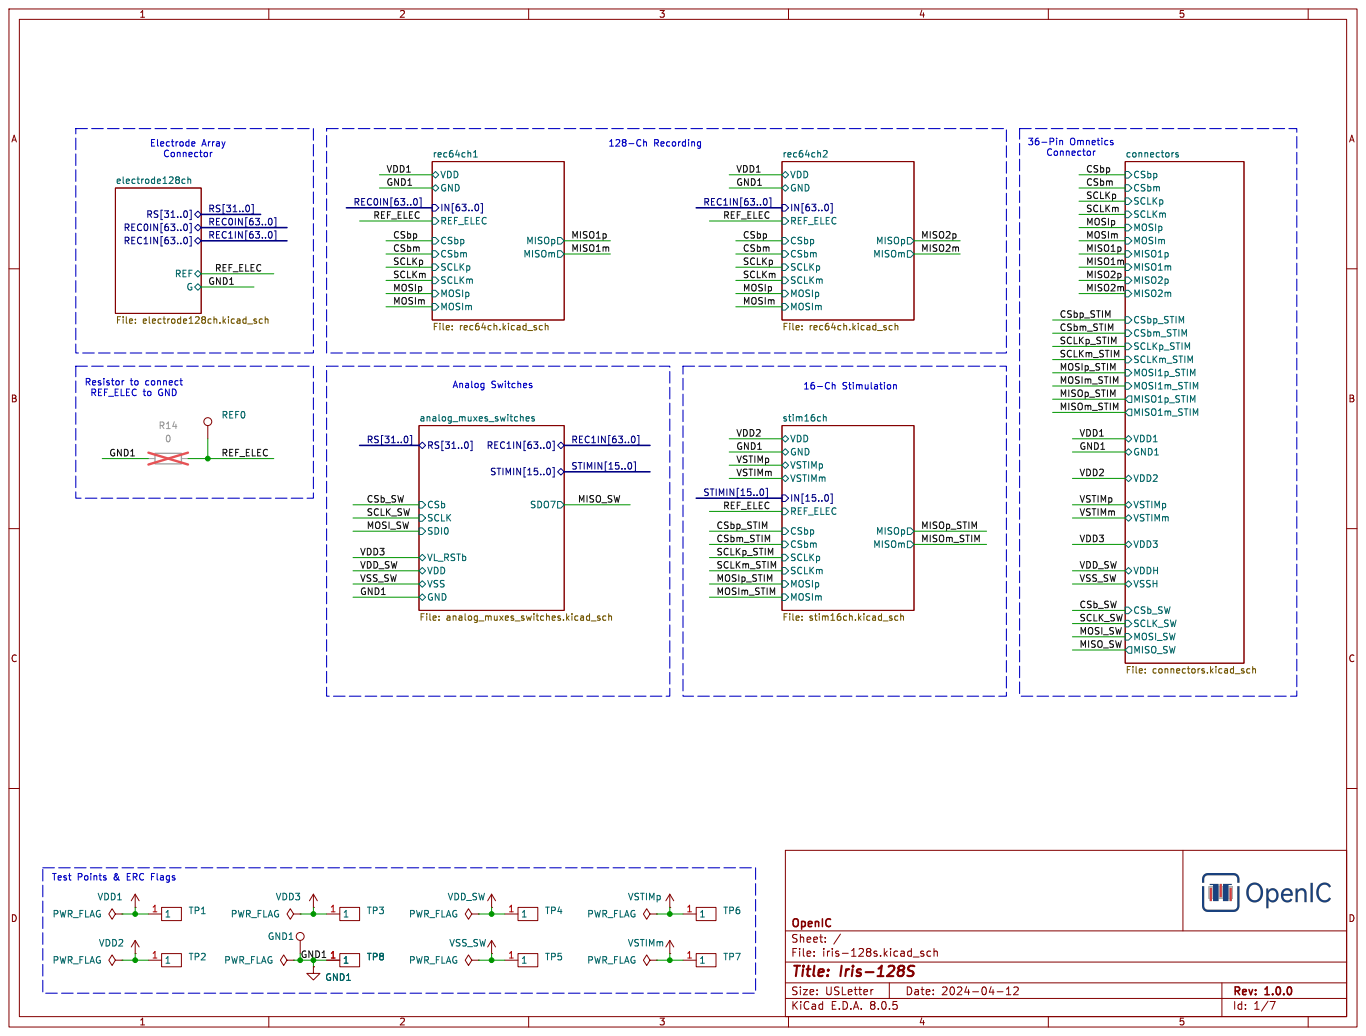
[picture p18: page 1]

connectors File: connectors.kicad_sch CSbm
CSbp VDD
IN[63..0] GND

Resistor to connect REF_ELEC to GND
Analog Switches Test Points & ERC Flags

File: iris-128s.kicad_sch Sheet: / OpenIC

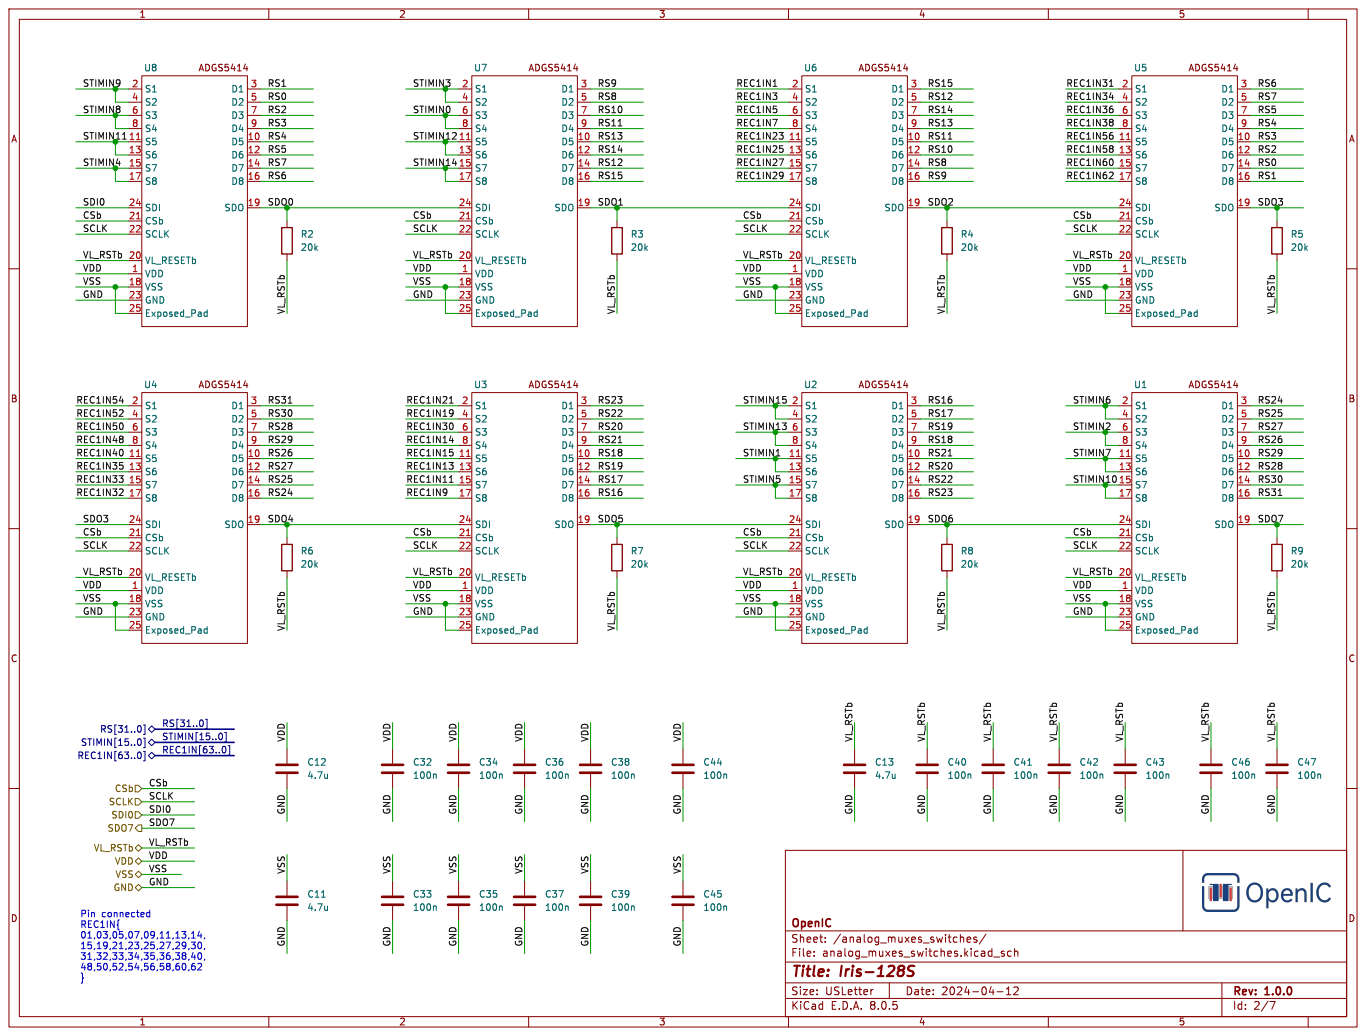
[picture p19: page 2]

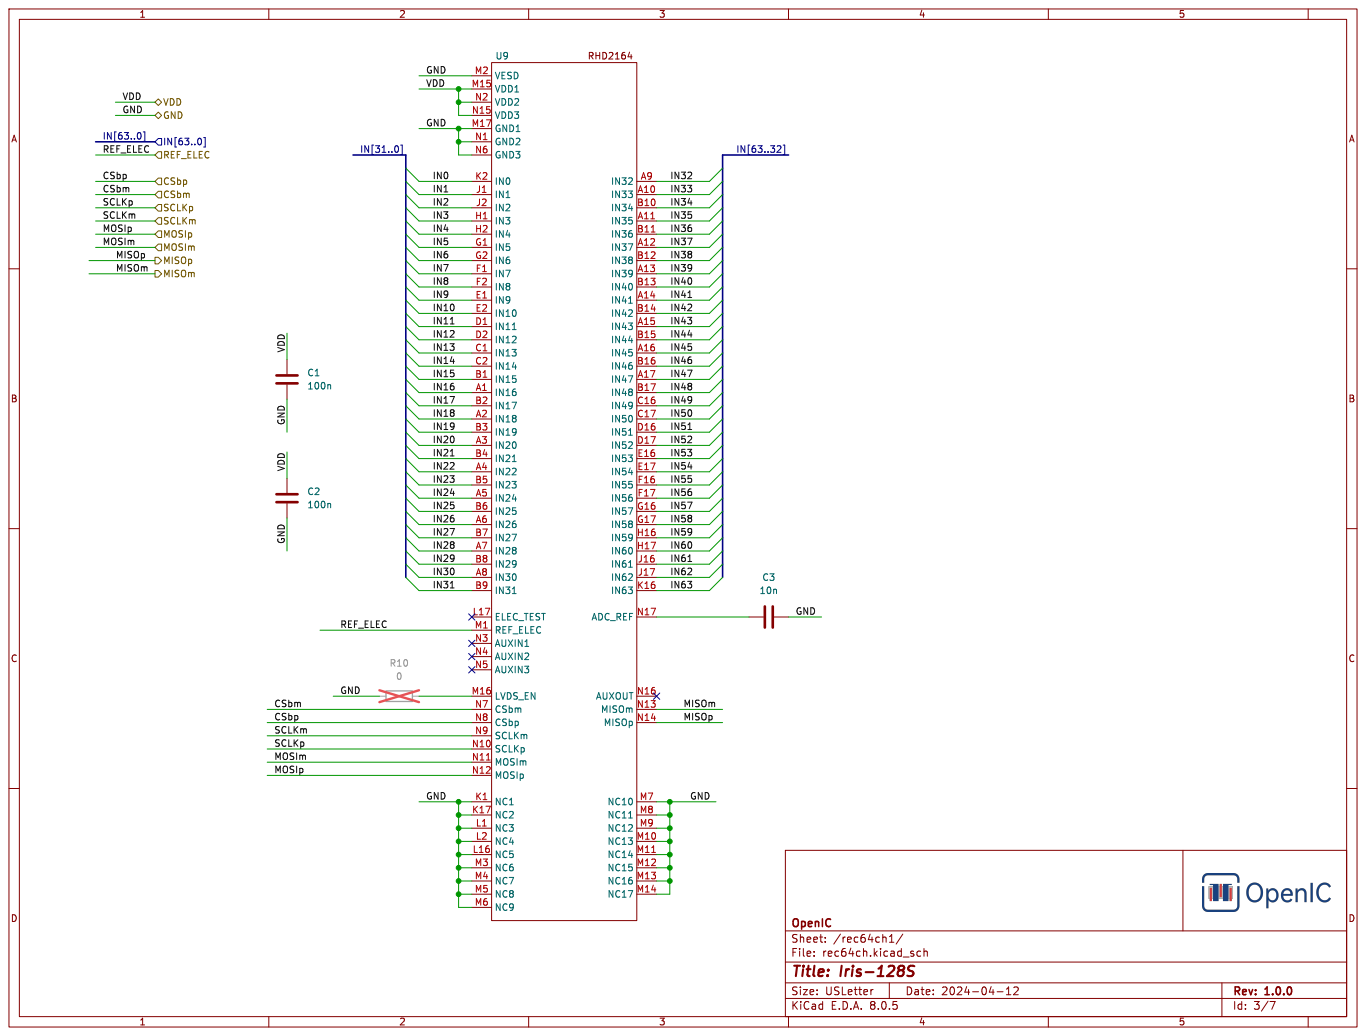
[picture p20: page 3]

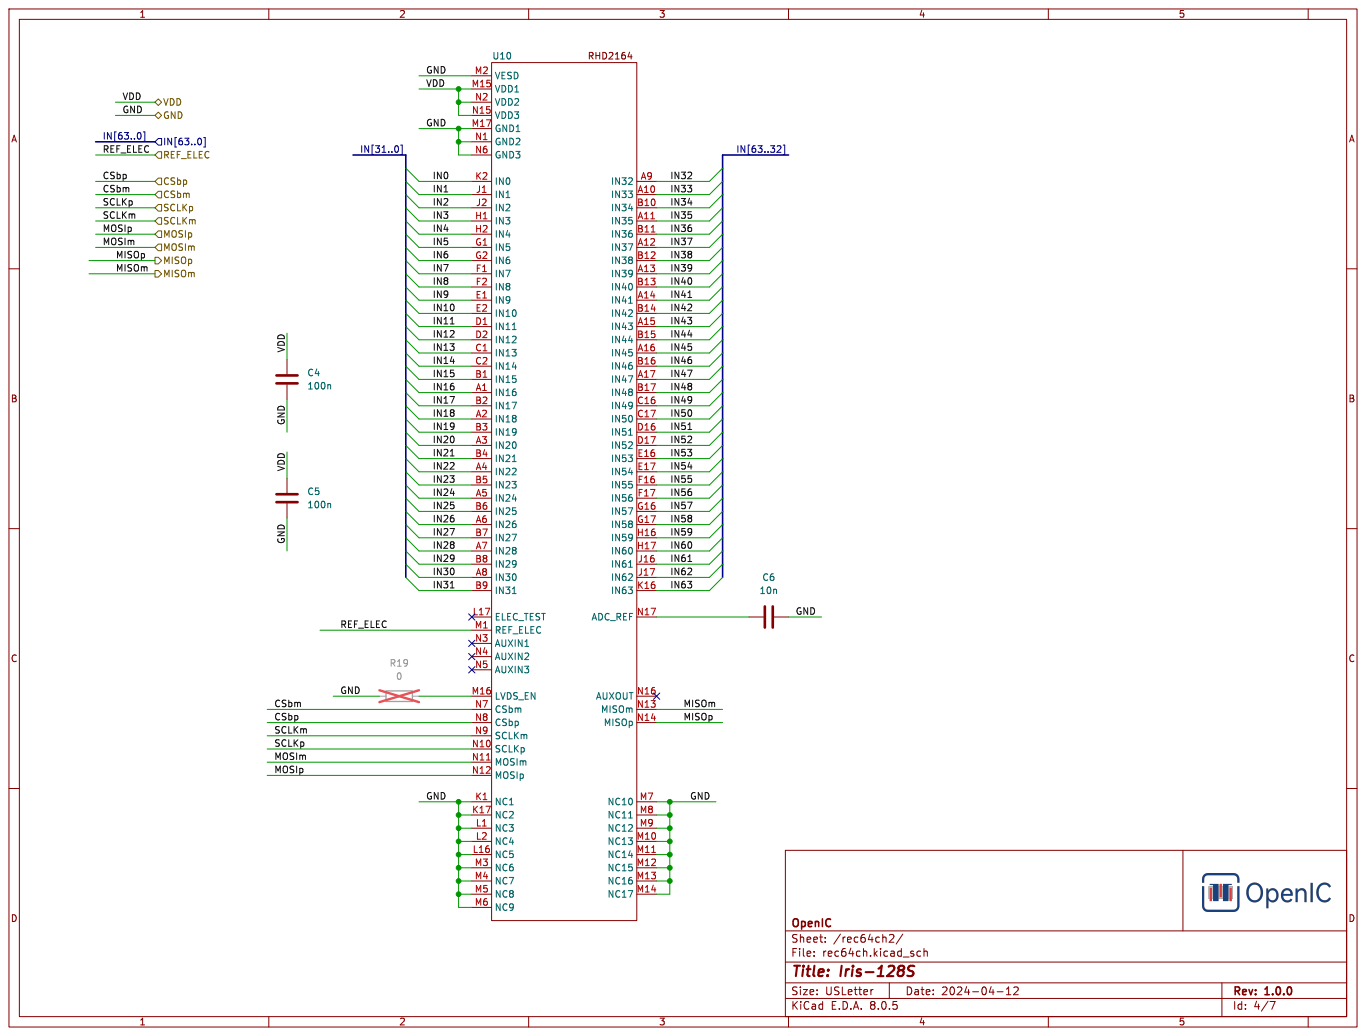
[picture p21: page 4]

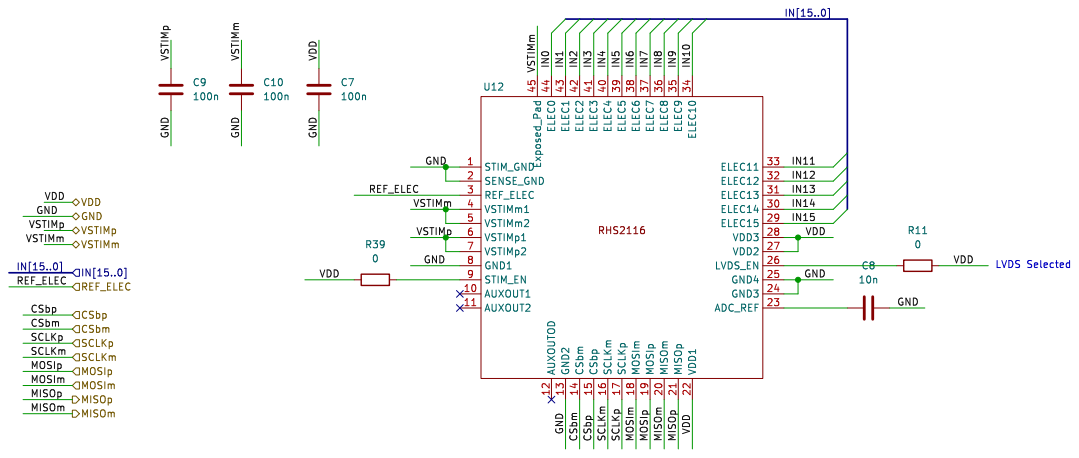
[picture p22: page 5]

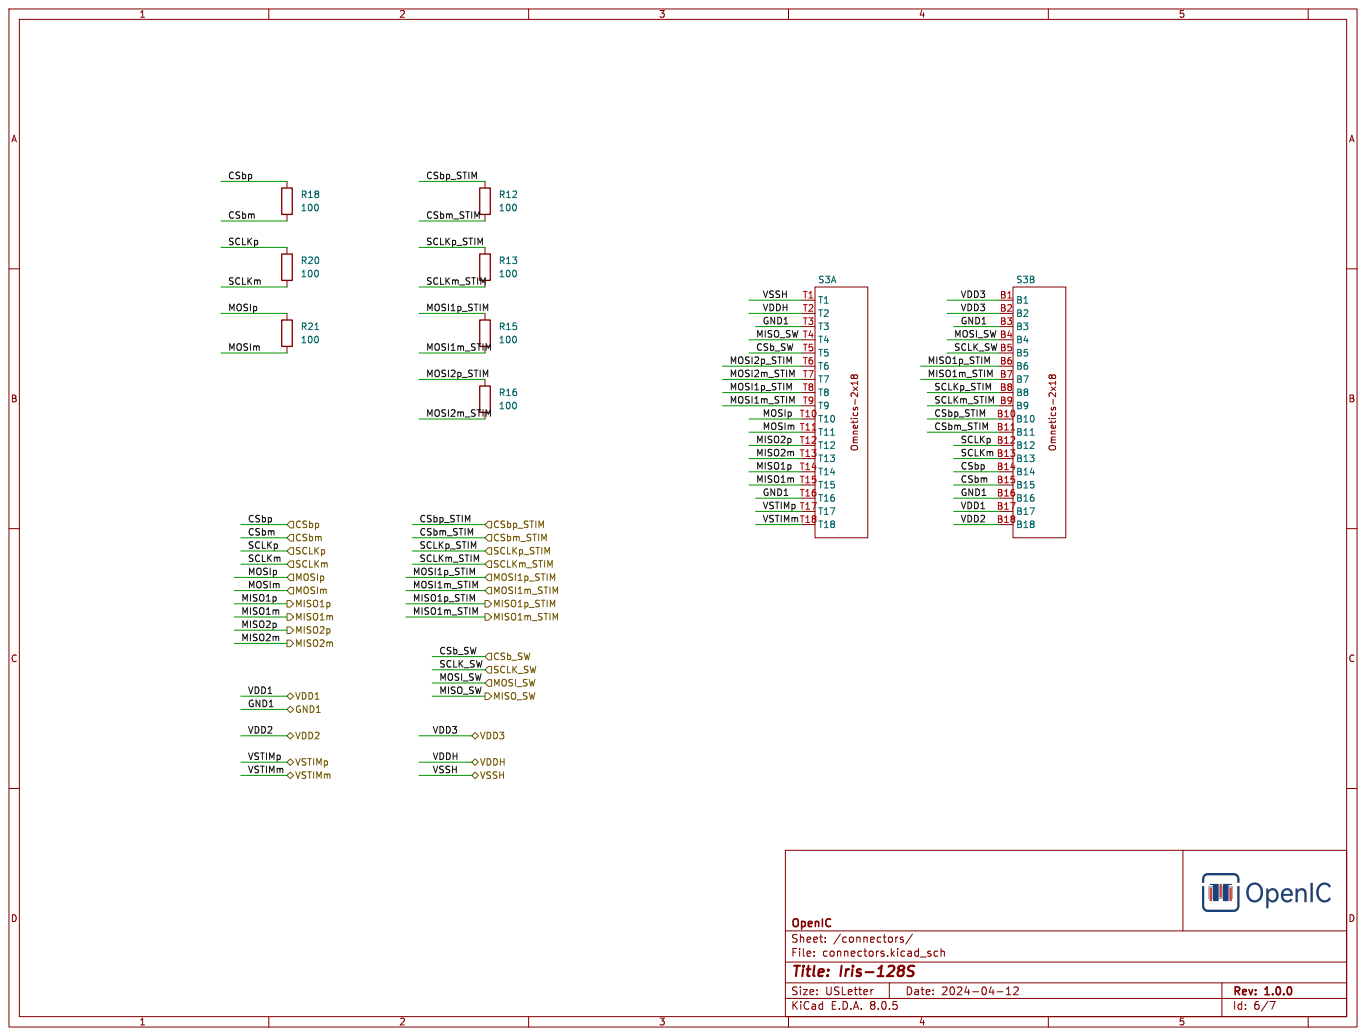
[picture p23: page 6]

File: connectors.kicad_sch Sheet: /connectors/ OpenIC

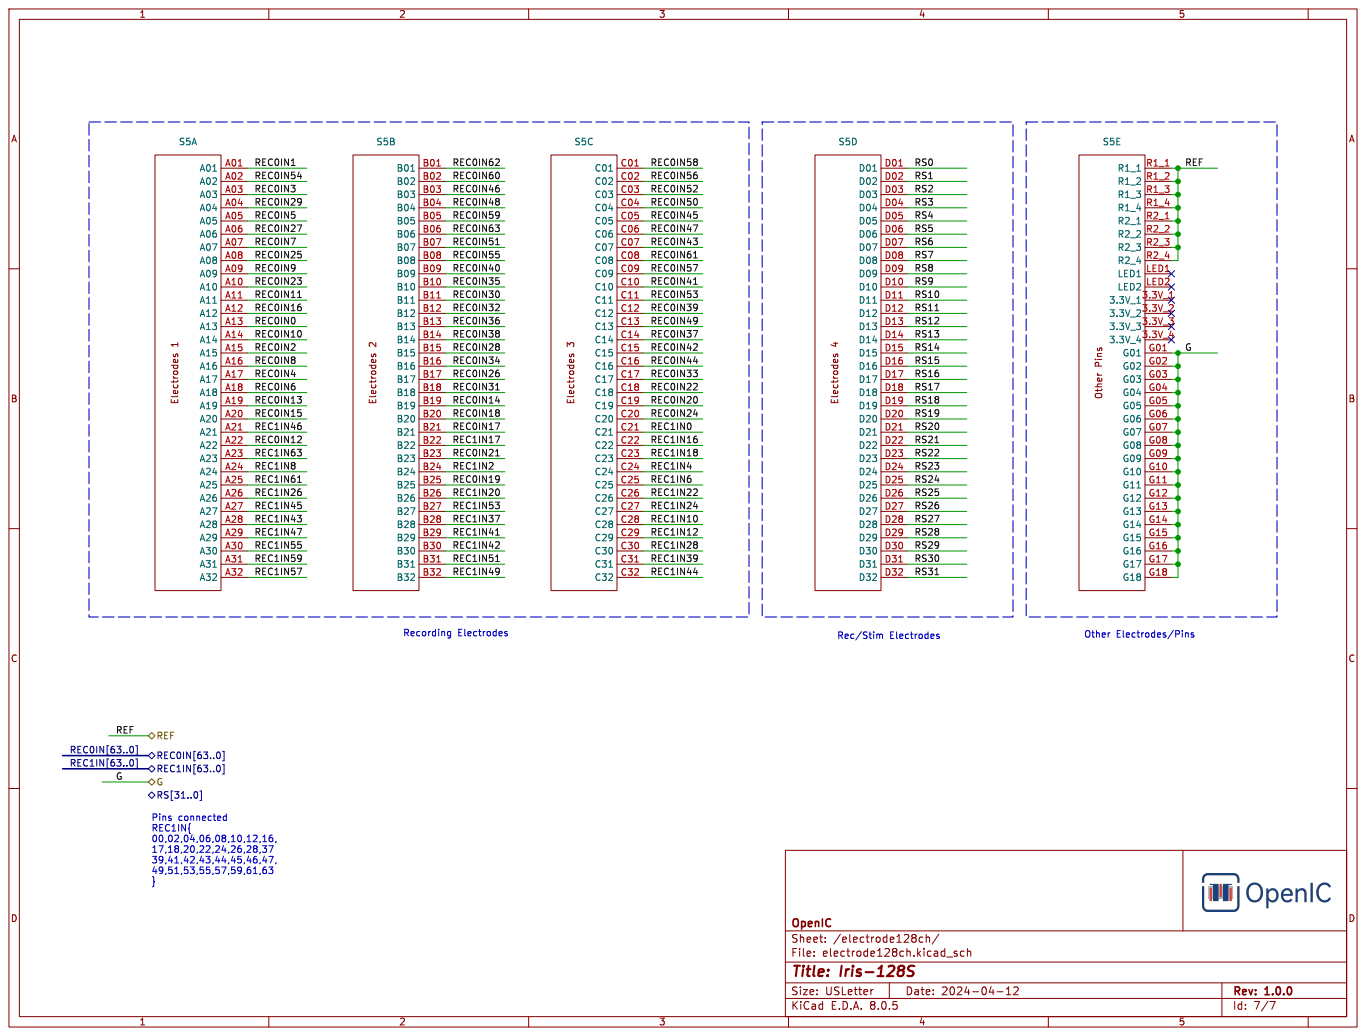
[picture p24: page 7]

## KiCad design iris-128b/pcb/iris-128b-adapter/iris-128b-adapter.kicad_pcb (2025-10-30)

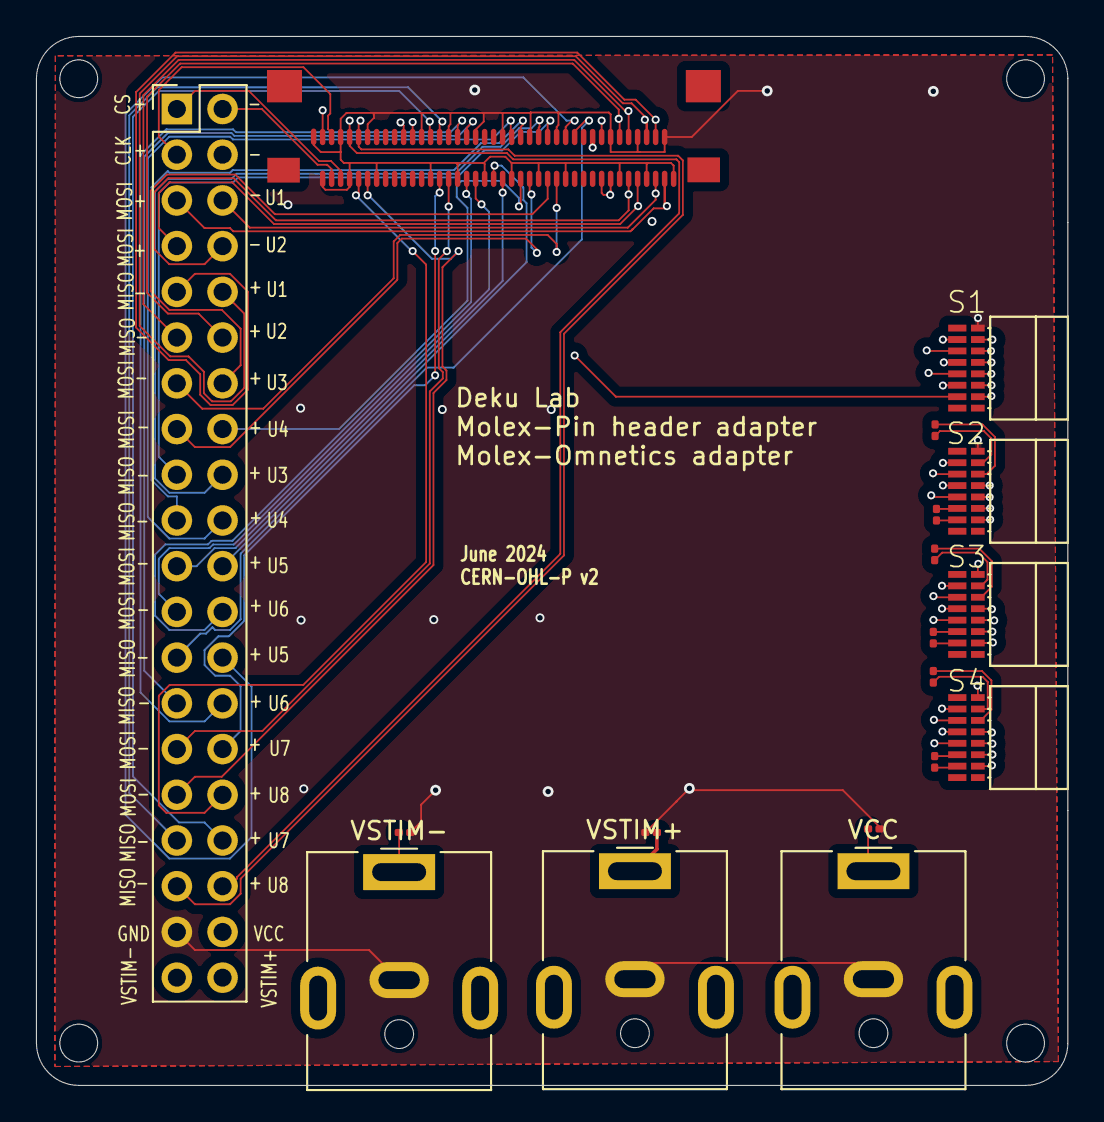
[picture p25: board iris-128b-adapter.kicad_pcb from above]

Board: 4 copper layers, 57.3 x 58.3 mm, 22 parts (0 on the bottom side), 38 nets.

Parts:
C1, C2, C3: 10 uF; C_0201_0603Metric
H1, H2, H3, H4: MountingHole; MountingHole_2.1mm
J1: Conn_01x40_Pin; PinHeader_2x20_P2.54mm_Vertical
J2: Conn_02x40_Row_Letter_First; molex
R1, R2, R3, R4, R5, R6: R_US; R_0201_0603Metric
S1, S2, S3, S4: OMNETICS_PZN-16-AA
VCC: Barrel_Jack_MountingPin; BarrelJack_CUI_PJ-063AH_Horizontal
VSTIM+: Barrel_Jack_MountingPin; BarrelJack_CUI_PJ-063AH_Horizontal
VSTIM-: Barrel_Jack_MountingPin; BarrelJack_CUI_PJ-063AH_Horizontal

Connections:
/CS+: J1.2, J2.a39, S1.B6 (~CS+)
/CS-: J1.1, J2.a38, S1.B7 (~CS-)
/S1_MISO1+: J1.10, J2.b3, S1.T7 (MISO1+)
/S1_MISO1-: J1.9, J2.b2, S1.T6 (MISO1-)
/S1_MISO2+: J1.12, J2.b6, S1.B2 (MISO2+)
/S1_MISO2-: J1.11, J2.b5, S1.B3 (MISO2-)
/S1_MOSI1+: J1.6, J2.a3, S1.T5 (MOSI1+)
/S1_MOSI1-: J1.5, J2.a2, S1.T4 (MOSI1-)
/S1_MOSI2+: J1.8, J2.a6, S1.B4 (MOSI2+)
/S1_MOSI2-: J1.7, J2.a5, S1.B5 (MOSI2-)
/S2_MISO1+: J1.18, J2.b15, S2.T7 (MISO1+)
/S2_MISO1-: J1.17, J2.b14, S2.T6 (MISO1-)
/S2_MISO2+: J1.20, J2.b18, S2.B2 (MISO2+)
/S2_MISO2-: J1.19, J2.b17, S2.B3 (MISO2-)
/S2_MOSI1+: J1.14, J1.16, J2.a15, J2.a18, S2.B4 (MOSI2+), S2.T5 (MOSI1+)
/S2_MOSI1-: J1.13, J1.15, J2.a14, J2.a17, S2.B5 (MOSI2-), S2.T4 (MOSI1-)
/S3_MISO1+: J1.26, J2.b12, J2.b21, S3.T7 (MISO1+)
/S3_MISO1-: J1.25, J2.b11, J2.b20, S3.T6 (MISO1-)
/S3_MISO2+: J1.28, J2.b24, S3.B2 (MISO2+)
/S3_MISO2-: J1.27, J2.b23, S3.B3 (MISO2-)
/S3_MOSI1+: J1.22, J2.a21, S3.T5 (MOSI1+)
/S3_MOSI1-: J1.21, J2.a20, S3.T4 (MOSI1-)
/S3_MOSI2+: J1.24, J2.a24, S3.B4 (MOSI2+)
/S3_MOSI2-: J1.23, J2.a23, S3.B5 (MOSI2-)
/S4_MISO1+: J1.34, J2.b27, S4.T7 (MISO1+)
/S4_MISO1-: J1.33, J2.b26, S4.T6 (MISO1-)
/S4_MISO2+: J1.36, J2.b36, S4.B2 (MISO2+)
/S4_MISO2-: J1.35, J2.b35, S4.B3 (MISO2-)
/S4_MOSI1+: J1.30, J2.a27, S4.T5 (MOSI1+)
/S4_MOSI1-: J1.29, J2.a26, S4.T4 (MOSI1-)
/S4_MOSI2+: J1.32, J2.a36, S4.B4 (MOSI2+)
/S4_MOSI2-: J1.31, J2.a35, S4.B5 (MOSI2-)
/SCLK+: J1.4, J2.b39, S1.T3 (SCLK+)
/SCLK-: J1.3, J2.b38, S1.T2 (SCLK-)
GND: C1.2, C2.2, C3.2, J1.37, J2.a1, J2.a4, J2.a7, J2.a13, J2.a16, J2.a19, J2.a22, J2.a25, J2.a28, J2.a34, J2.a37, J2.a40, J2.b1, J2.b4, J2.b7, J2.b13, J2.b16, J2.b19, J2.b22, J2.b25, J2.b28, J2.b34, J2.b37, J2.b40, S1.B8 (GND), S2.B8 (GND), S3.B8 (GND), S4.B8 (GND), VCC.2, VSTIM+.2, VSTIM-.2
VCC: C1.1, J1.38, J2.a8, J2.a9, VCC.1
VSTIM+: C2.1, J1.40, J2.b8, J2.b29, VSTIM+.1
VSTIM-: C3.1, J1.39, J2.b9, J2.b30, VSTIM-.1

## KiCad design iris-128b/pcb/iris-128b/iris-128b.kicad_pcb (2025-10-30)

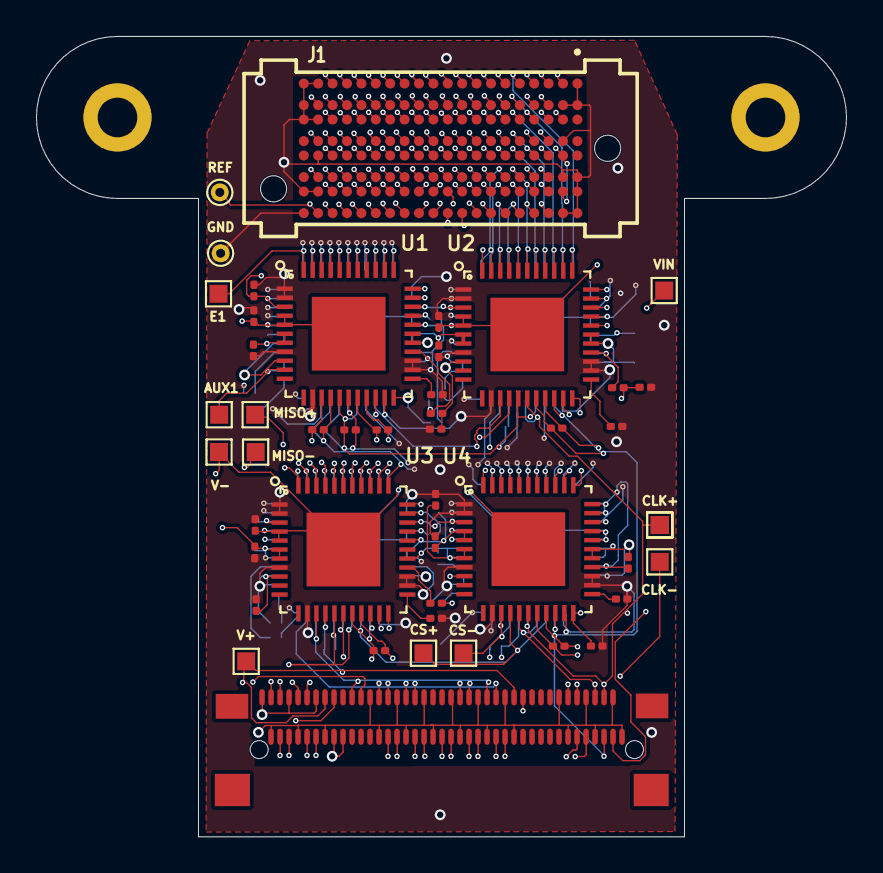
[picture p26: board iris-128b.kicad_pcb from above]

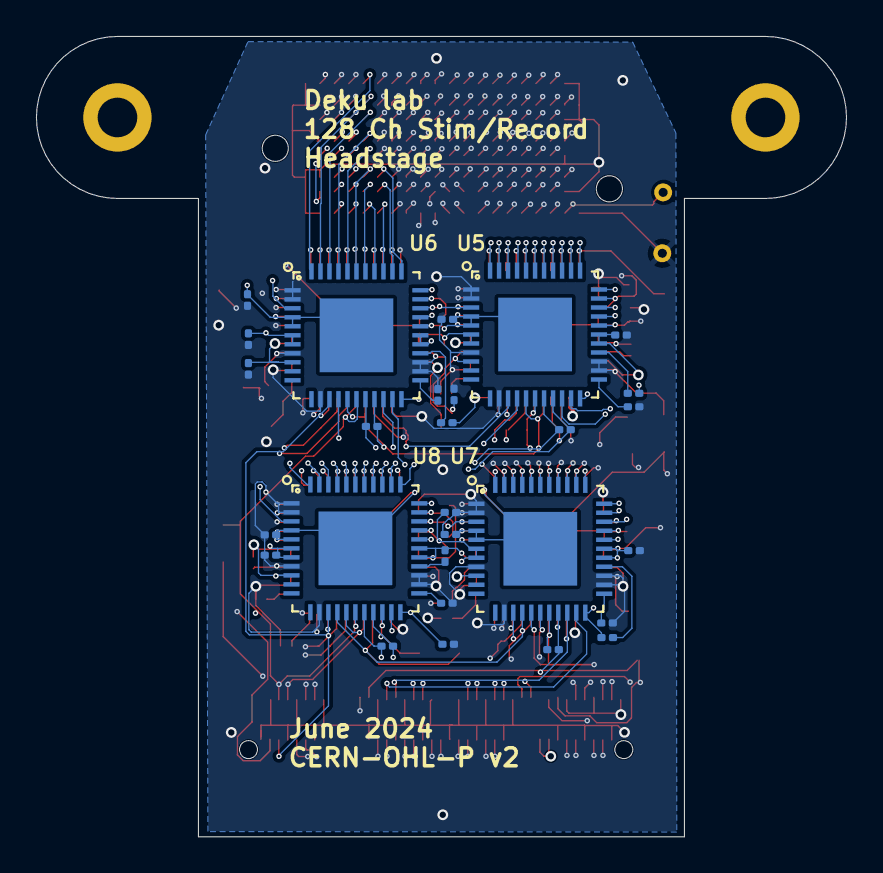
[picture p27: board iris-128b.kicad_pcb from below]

Board: 8 copper layers, 45.0 x 44.5 mm, 77 parts (28 on the bottom side), 184 nets.

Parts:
AUX1: TestPoint; TestPoint_Pad_1.0x1.0mm
C1, C2, C3, C4, C5, C6, C7, C8, C9, C10, C11, C12, C13, C14, C15, C16, C17, C18, C19, C20, C21, C22, C23, C24: 100 nF; C_0201_0603Metric
C25, C26, C27, C28, C29, C30, C31, C32: 10 nF; C_0201_0603Metric
CLK+: TestPoint; TestPoint_Pad_1.0x1.0mm
CLK+#2: TestPoint; TestPoint_Pad_1.0x1.0mm
CLK-: TestPoint; TestPoint_Pad_1.0x1.0mm
CS+: TestPoint; TestPoint_Pad_1.0x1.0mm
CS-: TestPoint; TestPoint_Pad_1.0x1.0mm
E1: TestPoint; TestPoint_Pad_1.0x1.0mm
GND: TESTPOINT_SMALL; TestPoint_THTPad_D1.0mm_Drill0.5mm
H1, H2: MountingHole; MountingHole_2.2mm_M2_DIN965_Pad
J1: SEAM8-20-S02.0-X-08-3; SAMTEC_SEAM8-20-S02.0-X-08-3
J2: Conn_02x40_Row_Letter_First; molex
LVDS1, LVDS2, LVDS3, LVDS4, LVDS5, LVDS6, LVDS7, LVDS8: 0; R_0201_0603Metric
MISO+: TestPoint; TestPoint_Pad_1.0x1.0mm
MISO-: TestPoint; TestPoint_Pad_1.0x1.0mm
R1: 0; R_0201_0603Metric
R2, R3, R4, R5, R6, R7, R8, R9, R10, R11: 100; R_0201_0603Metric
REF: TESTPOINT_SMALL; TestPoint_THTPad_D1.0mm_Drill0.5mm
U1, U2, U3, U4, U5, U6, U7, U8: QFN44_7_X_7
V+: TestPoint; TestPoint_Pad_1.0x1.0mm
V-: TestPoint; TestPoint_Pad_1.0x1.0mm
VIN: VCC; TestPoint_Pad_1.0x1.0mm

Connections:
/CS+: CS+.1, J2.b39, R10.1, U1.15 (~CS+), U2.15 (~CS+), U3.15 (~CS+), U4.15 (~CS+), U5.15 (~CS+), U6.15 (~CS+), U7.15 (~CS+), U8.15 (~CS+)
/CS-: CS-.1, J2.b38, R10.2, U1.14 (~CS-), U2.14 (~CS-), U3.14 (~CS-), U4.14 (~CS-), U5.14 (~CS-), U6.14 (~CS-), U7.14 (~CS-), U8.14 (~CS-)
/Chip1-Elec0: E1.1, J1.C1-E0 (A01), U1.44 (ELEC0)
/Chip1-Elec1: J1.C1-E1 (A02), U1.43 (ELEC1)
/Chip1-Elec2: J1.C1-E2 (B01), U1.42 (ELEC2)
/Chip1-Elec3: J1.C1-E3 (B02), U1.41 (ELEC3)
/Chip1-Elec4: J1.C1-E4 (C01), U1.40 (ELEC4)
/Chip1-Elec5: J1.C1-E5 (C02), U1.39 (ELEC5)
/Chip1-Elec6: J1.C1-E6 (D01), U1.38 (ELEC6)
/Chip1-Elec7: J1.C1-E7 (D02), U1.37 (ELEC7)
/Chip1-Elec8: J1.C1-E8 (A03), U1.36 (ELEC8)
/Chip1-Elec9: J1.C1-E9 (A04), U1.35 (ELEC9)
/Chip1-Elec10: J1.C1-E10 (B03), U1.34 (ELEC10)
/Chip1-Elec11: J1.C1-E11 (B04), U1.33 (ELEC11)
/Chip1-Elec12: J1.C1-E12 (C03), U1.32 (ELEC12)
/Chip1-Elec13: J1.C1-E13 (C04), U1.31 (ELEC13)
/Chip1-Elec14: J1.C1-E14 (D03), U1.30 (ELEC14)
/Chip1-Elec15: J1.C1-E15 (D04), U1.29 (ELEC15)
/Chip2-Elec0: J1.C2-E0 (A27), U2.44 (ELEC0)
/Chip2-Elec1: J1.C2-E1 (A28), U2.43 (ELEC1)
/Chip2-Elec2: J1.C2-E2 (B27), U2.42 (ELEC2)
/Chip2-Elec3: J1.C2-E3 (B28), U2.41 (ELEC3)
/Chip2-Elec4: J1.C2-E4 (C27), U2.40 (ELEC4)
/Chip2-Elec5: J1.C2-E5 (C28), U2.39 (ELEC5)
/Chip2-Elec6: J1.C2-E6 (D27), U2.38 (ELEC6)
/Chip2-Elec8: J1.C2-E8 (D26), U2.36 (ELEC8)
/Chip2-Elec9: J1.C2-E9 (D25), U2.35 (ELEC9)
/Chip2-Elec10: J1.C2-E10 (C26), U2.34 (ELEC10)
/Chip2-Elec11: J1.C2-E11 (C25), U2.33 (ELEC11)
/Chip2-Elec12: J1.C2-E12 (B26), U2.32 (ELEC12)
/Chip2-Elec13: J1.C2-E13 (B25), U2.31 (ELEC13)
/Chip2-Elec14: J1.C2-E14 (A26), U2.30 (ELEC14)
/Chip2-Elec15: J1.C2-E15 (A25), U2.29 (ELEC15)
/Chip3-Elec0: J1.C3-E0 (NC), U3.44 (ELEC0)
/Chip3-Elec1: J1.C3-E1 (NC), U3.43 (ELEC1)
/Chip3-Elec2: J1.C3-E2 (NC), U3.42 (ELEC2)
/Chip3-Elec3: J1.C3-E3 (NC), U3.41 (ELEC3)
/Chip3-Elec4: J1.C3-E4 (C09), U3.40 (ELEC4)
/Chip3-Elec5: J1.C3-E5 (C10), U3.39 (ELEC5)
/Chip3-Elec6: J1.C3-E6 (D09), U3.38 (ELEC6)
/Chip3-Elec7: J1.C3-E7 (D10), U3.37 (ELEC7)
/Chip3-Elec8: J1.C3-E8 (A11), U3.36 (ELEC8)
/Chip3-Elec9: J1.C3-E9 (A12), U3.35 (ELEC9)
/Chip3-Elec10: J1.C3-E10 (D12), U3.34 (ELEC10)
/Chip3-Elec11: J1.C3-E11 (D11), U3.33 (ELEC11)
/Chip3-Elec12: J1.C3-E12 (C12), U3.32 (ELEC12)
/Chip3-Elec13: J1.C3-E13 (C11), U3.31 (ELEC13)
/Chip3-Elec14: J1.C3-E14 (B12), U3.30 (ELEC14)
/Chip3-Elec15: J1.C3-E15 (B11), U3.29 (ELEC15)
/Chip4-Elec0: J1.C4-E0 (A20), U4.44 (ELEC0)
/Chip4-Elec1: J1.C4-E1 (A22), U4.43 (ELEC1)
/Chip4-Elec2: J1.C4-E2 (A24), U4.42 (ELEC2)
/Chip4-Elec3: J1.C4-E3 (B17), U4.41 (ELEC3)
/Chip4-Elec4: J1.C4-E4 (B19), U4.40 (ELEC4)
/Chip4-Elec5: J1.C4-E5 (B21), U4.39 (ELEC5)
/Chip4-Elec6: J1.C4-E6 (B23), U4.38 (ELEC6)
/Chip4-Elec7: J1.C4-E7 (B20), U4.37 (ELEC7)
/Chip4-Elec8: J1.C4-E8 (B22), U4.36 (ELEC8)
/Chip4-Elec9: J1.C4-E9 (B24), U4.35 (ELEC9)
/Chip4-Elec10: J1.C4-E10 (C23), U4.34 (ELEC10)
/Chip4-Elec11: J1.C4-E11 (A18), U4.33 (ELEC11)
/Chip4-Elec12: J1.C4-E12 (A23), U4.32 (ELEC12)
/Chip4-Elec13: J1.C4-E13 (A21), U4.31 (ELEC13)
/Chip4-Elec14: J1.C4-E14 (A19), U4.30 (ELEC14)
/Chip4-Elec15: J1.C4-E15 (A17), U4.29 (ELEC15)
/Chip5-Elec0: J1.C5-E0 (A08), U5.44 (ELEC0)
/Chip5-Elec1: J1.C5-E1 (B07), U5.43 (ELEC1)
/Chip5-Elec2: J1.C5-E2 (B08), U5.42 (ELEC2)
/Chip5-Elec3: J1.C5-E3 (C07), U5.41 (ELEC3)
/Chip5-Elec4: J1.C5-E4 (C08), U5.40 (ELEC4)
/Chip5-Elec5: J1.C5-E5 (D07), U5.39 (ELEC5)
/Chip5-Elec6: J1.C5-E6 (D08), U5.38 (ELEC6)
/Chip5-Elec7: J1.C5-E7 (A07), U5.37 (ELEC7)
/Chip5-Elec8: J1.C5-E8 (D06), U5.36 (ELEC8)
/Chip5-Elec9: J1.C5-E9 (D05), U5.35 (ELEC9)
/Chip5-Elec10: J1.C5-E10 (C06), U5.34 (ELEC10)
/Chip5-Elec11: J1.C5-E11 (C05), U5.33 (ELEC11)
/Chip5-Elec12: J1.C5-E12 (B06), U5.32 (ELEC12)
/Chip5-Elec13: J1.C5-E13 (B05), U5.31 (ELEC13)
/Chip5-Elec14: J1.C5-E14 (A06), U5.30 (ELEC14)
/Chip5-Elec15: J1.C5-E15 (A05), U5.29 (ELEC15)
/Chip6-Elec0: J1.C6-E0 (D28), U6.44 (ELEC0)
/Chip6-Elec1: J1.C6-E1 (D27), U6.43 (ELEC1)
/Chip6-Elec2: J1.C6-E2 (C28), U6.42 (ELEC2)
/Chip6-Elec3: J1.C6-E3 (C27), U6.41 (ELEC3)
/Chip6-Elec4: J1.C6-E4 (B28), U6.40 (ELEC4)
/Chip6-Elec5: J1.C6-E5 (B27), U6.39 (ELEC5)
/Chip6-Elec6: J1.C6-E6 (A28), U6.38 (ELEC6)
/Chip6-Elec7: J1.C6-E7 (A27), U6.37 (ELEC7)
/Chip6-Elec8: J1.C6-E8 (D26), U6.36 (ELEC8)
/Chip6-Elec9: J1.C6-E9 (D25), U6.35 (ELEC9)
/Chip6-Elec10: J1.C6-E10 (C26), U6.34 (ELEC10)
/Chip6-Elec11: J1.C6-E11 (A26), U6.33 (ELEC11)
/Chip6-Elec12: J1.C6-E12 (B25), U6.32 (ELEC12)
/Chip6-Elec13: J1.C6-E13 (B26), U6.31 (ELEC13)
/Chip6-Elec14: J1.C6-E14 (C25), U6.30 (ELEC14)
/Chip6-Elec15: J1.C6-E15 (A25), U6.29 (ELEC15)
/Chip7-Elec0: J1.C7-E0 (C16), U7.44 (ELEC0)
/Chip7-Elec1: J1.C7-E1 (D15), U7.43 (ELEC1)
/Chip7-Elec2: J1.C7-E2 (D16), U7.42 (ELEC2)
/Chip7-Elec3: J1.C7-E3 (D14), U7.41 (ELEC3)
/Chip7-Elec4: J1.C7-E4 (D13), U7.40 (ELEC4)
/Chip7-Elec5: J1.C7-E5 (C14), U7.39 (ELEC5)
/Chip7-Elec6: J1.C7-E6 (C13), U7.38 (ELEC6)
/Chip7-Elec7: J1.C7-E7 (B14), U7.37 (ELEC7)
/Chip7-Elec8: J1.C7-E8 (B13), U7.36 (ELEC8)
/Chip7-Elec9: J1.C7-E9 (A14), U7.35 (ELEC9)
/Chip7-Elec10: J1.C7-E10 (A13), U7.34 (ELEC10)
/Chip7-Elec11: J1.C7-E11 (A15), U7.33 (ELEC11)
/Chip7-Elec12: J1.C7-E12 (A16), U7.32 (ELEC12)
/Chip7-Elec13: J1.C7-E13 (B15), U7.31 (ELEC13)
/Chip7-Elec14: J1.C7-E14 (B16), U7.30 (ELEC14)
/Chip7-Elec15: J1.C7-E15 (C15), U7.29 (ELEC15)
/Chip8-Elec0: J1.C8-E0 (C21), U8.44 (ELEC0)
/Chip8-Elec1: J1.C8-E1 (C19), U8.43 (ELEC1)
/Chip8-Elec2: J1.C8-E2 (C24), U8.42 (ELEC2)
/Chip8-Elec3: J1.C8-E3 (C22), U8.41 (ELEC3)
/Chip8-Elec4: J1.C8-E4 (C20), U8.40 (ELEC4)
/Chip8-Elec5: J1.C8-E5 (D23), U8.39 (ELEC5)
/Chip8-Elec6: J1.C8-E6 (D21), U8.38 (ELEC6)
/Chip8-Elec7: J1.C8-E7 (D19), U8.37 (ELEC7)
/Chip8-Elec8: J1.C8-E8 (D24), U8.36 (ELEC8)
/Chip8-Elec9: J1.C8-E9 (D22), U8.35 (ELEC9)
/Chip8-Elec10: J1.C8-E10 (D20), U8.34 (ELEC10)
/Chip8-Elec11: J1.C8-E11 (B18), U8.33 (ELEC11)
/Chip8-Elec12: J1.C8-E12 (C17), U8.32 (ELEC12)
/Chip8-Elec13: J1.C8-E13 (C18), U8.31 (ELEC13)
/Chip8-Elec14: J1.C8-E14 (D17), U8.30 (ELEC14)
/Chip8-Elec15: J1.C8-E15 (D18), U8.29 (ELEC15)
/Net-(CHIP1-MISO+): J2.a3, MISO+.1, U1.21 (MISO+)
/Net-(CHIP1-MISO-): J2.a2, MISO-.1, U1.20 (MISO-)
/Net-(CHIP1-MOSI+): J2.b3, R2.2, U1.19 (MOSI+)
/Net-(CHIP1-MOSI-): J2.b2, R2.1, U1.18 (MOSI-)
/Net-(CHIP2-MISO+): J2.a6, U2.21 (MISO+)
/Net-(CHIP2-MISO-): J2.a5, U2.20 (MISO-)
/Net-(CHIP2-MOSI+): J2.b6, R3.2, U2.19 (MOSI+)
/Net-(CHIP2-MOSI-): J2.b5, R3.1, U2.18 (MOSI-)
/Net-(CHIP3-MOSI+): J2.b15, R4.2, U3.19 (MOSI+)
/Net-(CHIP3-MOSI-): J2.b14, R4.1, U3.18 (MOSI-)
/Net-(CHIP4-MOSI+): J2.b18, R5.2, U4.19 (MOSI+)
/Net-(CHIP4-MOSI-): J2.b17, R5.1, U4.18 (MOSI-)
/Net-(CHIP5-MOSI+): J2.b21, R6.2, U5.19 (MOSI+)
/Net-(CHIP5-MOSI-): J2.b20, R6.1, U5.18 (MOSI-)
/Net-(CHIP6-MOSI+): J2.b24, R7.2, U6.19 (MOSI+)
/Net-(CHIP6-MOSI-): J2.b23, R7.1, U6.18 (MOSI-)
/Net-(CHIP7-MOSI+): J2.b27, R8.2, U7.19 (MOSI+)
/Net-(CHIP7-MOSI-): J2.b26, R8.1, U7.18 (MOSI-)
/Net-(CHIP8-MOSI+): J2.b36, R9.2, U8.19 (MOSI+)
/Net-(CHIP8-MOSI-): J2.b35, R9.1, U8.18 (MOSI-)
/Net-(U1-REF_ELEC): J1.R1, J1.R2 (NC), R1.2, REF.1
/SCLK+: CLK+.1, CLK+#2.1, J2.a39, R11.2, U1.17 (SCLK+), U2.17 (SCLK+), U3.17 (SCLK+), U4.17 (SCLK+), U5.17 (SCLK+), U6.17 (SCLK+), U7.17 (SCLK+), U8.17 (SCLK+)
/SCLK-: CLK-.1, J2.a38, R11.1, U1.16 (SCLK-), U2.16 (SCLK-), U3.16 (SCLK-), U4.16 (SCLK-), U5.16 (SCLK-), U6.16 (SCLK-), U7.16 (SCLK-), U8.16 (SCLK-)
CHIP3-MISO+: J2.a15, U3.21 (MISO+)
CHIP3-MISO-: J2.a14, U3.20 (MISO-)
CHIP4-MISO+: J2.a18, U4.21 (MISO+)
CHIP4-MISO-: J2.a17, U4.20 (MISO-)
CHIP5-MISO+: J2.a12, U5.21 (MISO+)
CHIP5-MISO-: J2.a11, U5.20 (MISO-)
CHIP6-MISO+: J2.a24, U6.21 (MISO+)
CHIP6-MISO-: J2.a23, U6.20 (MISO-)
CHIP7-MISO+: J2.a27, U7.21 (MISO+)
CHIP7-MISO-: J2.a26, U7.20 (MISO-)
CHIP8-MISO+: J2.a36, U8.21 (MISO+)
CHIP8-MISO-: J2.a35, U8.20 (MISO-)
GND: C1.2, C2.2, C3.2, C4.2, C5.2, C6.2, C7.2, C8.2, C9.2, C10.2, C11.2, C12.2, C13.2, C14.2, C15.2, C16.2, C17.2, C18.2, C19.2, C20.2, C21.2, C22.2, C23.2, C24.2, C25.2, C26.2, C27.2, C28.2, C29.2, C30.2, C31.2, C32.2, J1.G, J2.a1, J2.a4, J2.a7, J2.a13, J2.a16, J2.a19, J2.a22, J2.a25, J2.a28, J2.a34, J2.a37, J2.a40, J2.b1, J2.b4, J2.b7, J2.b13, J2.b16, J2.b19, J2.b22, J2.b25, J2.b28, J2.b34, J2.b37, J2.b40, R1.1, U1.1 (STIM_GND), U1.2 (SENSE_GND), U1.8 (GND1), U1.13 (GND2), U1.24 (GND3), U1.25 (GND4), U2.1 (STIM_GND), U2.2 (SENSE_GND), U2.8 (GND1), U2.13 (GND2), U2.24 (GND3), U2.25 (GND4), U3.1 (STIM_GND), U3.2 (SENSE_GND), U3.8 (GND1), U3.13 (GND2), U3.24 (GND3), U3.25 (GND4), U4.1 (STIM_GND), U4.2 (SENSE_GND), U4.8 (GND1), U4.13 (GND2), U4.24 (GND3), U4.25 (GND4), U5.1 (STIM_GND), U5.2 (SENSE_GND), U5.8 (GND1), U5.13 (GND2), U5.24 (GND3), U5.25 (GND4), U6.1 (STIM_GND), U6.2 (SENSE_GND), U6.8 (GND1), U6.13 (GND2), U6.24 (GND3), U6.25 (GND4), U7.1 (STIM_GND), U7.2 (SENSE_GND), U7.8 (GND1), U7.13 (GND2), U7.24 (GND3), U7.25 (GND4), U8.1 (STIM_GND), U8.2 (SENSE_GND), U8.8 (GND1), U8.13 (GND2), U8.24 (GND3), U8.25 (GND4)
unnamed: C25.1, U1.23 (ADC_REF)
unnamed: LVDS1.1, U1.26 (LVDS_EN)
unnamed: C26.1, U2.23 (ADC_REF)
unnamed: LVDS2.1, U2.26 (LVDS_EN)
unnamed: C27.1, U3.23 (ADC_REF)
unnamed: LVDS3.1, U3.26 (LVDS_EN)
unnamed: C28.1, U4.23 (ADC_REF)
unnamed: LVDS4.1, U4.26 (LVDS_EN)
unnamed: C29.1, U5.23 (ADC_REF)
unnamed: LVDS5.1, U5.26 (LVDS_EN)
unnamed: C30.1, U6.23 (ADC_REF)
unnamed: LVDS6.1, U6.26 (LVDS_EN)
unnamed: C31.1, U7.23 (ADC_REF)
unnamed: LVDS7.1, U7.26 (LVDS_EN)
unnamed: C32.1, U8.23 (ADC_REF)
unnamed: LVDS8.1, U8.26 (LVDS_EN)
V+: C1.1, C2.1, C3.1, C4.1, C5.1, C6.1, C7.1, C8.1, J2.a8, J2.a29, U1.6 (VSTIM+1), U1.7 (VSTIM+2), U2.6 (VSTIM+1), U2.7 (VSTIM+2), U3.6 (VSTIM+1), U3.7 (VSTIM+2), U4.6 (VSTIM+1), U4.7 (VSTIM+2), U5.6 (VSTIM+1), U5.7 (VSTIM+2), U6.6 (VSTIM+1), U6.7 (VSTIM+2), U7.6 (VSTIM+1), U7.7 (VSTIM+2), U8.6 (VSTIM+1), U8.7 (VSTIM+2), V+.1
V-: C17.1, C18.1, C19.1, C20.1, C21.1, C22.1, C23.1, C24.1, J2.a9, J2.a30, U1.4 (VSTIM-1), U1.5 (VSTIM-2), U1.CENTER (VSTIM-), U2.4 (VSTIM-1), U2.5 (VSTIM-2), U2.CENTER (VSTIM-), U3.4 (VSTIM-1), U3.5 (VSTIM-2), U3.CENTER (VSTIM-), U4.4 (VSTIM-1), U4.5 (VSTIM-2), U4.CENTER (VSTIM-), U5.4 (VSTIM-1), U5.5 (VSTIM-2), U5.CENTER (VSTIM-), U6.4 (VSTIM-1), U6.5 (VSTIM-2), U6.CENTER (VSTIM-), U7.4 (VSTIM-1), U7.5 (VSTIM-2), U7.CENTER (VSTIM-), U8.4 (VSTIM-1), U8.5 (VSTIM-2), U8.CENTER (VSTIM-), V-.1
VCC: C9.1, C10.1, C11.1, C12.1, C13.1, C14.1, C15.1, C16.1, J2.b8, J2.b9, LVDS1.2, LVDS2.2, LVDS3.2, LVDS4.2, LVDS5.2, LVDS6.2, LVDS7.2, LVDS8.2, U1.9 (STIM_EN), U1.22 (VDD1), U1.27 (VDD2), U1.28 (VDD3), U2.9 (STIM_EN), U2.22 (VDD1), U2.27 (VDD2), U2.28 (VDD3), U3.9 (STIM_EN), U3.22 (VDD1), U3.27 (VDD2), U3.28 (VDD3), U4.9 (STIM_EN), U4.22 (VDD1), U4.27 (VDD2), U4.28 (VDD3), U5.9 (STIM_EN), U5.22 (VDD1), U5.27 (VDD2), U5.28 (VDD3), U6.9 (STIM_EN), U6.22 (VDD1), U6.27 (VDD2), U6.28 (VDD3), U7.9 (STIM_EN), U7.22 (VDD1), U7.27 (VDD2), U7.28 (VDD3), U8.9 (STIM_EN), U8.22 (VDD1), U8.27 (VDD2), U8.28 (VDD3), VIN.1

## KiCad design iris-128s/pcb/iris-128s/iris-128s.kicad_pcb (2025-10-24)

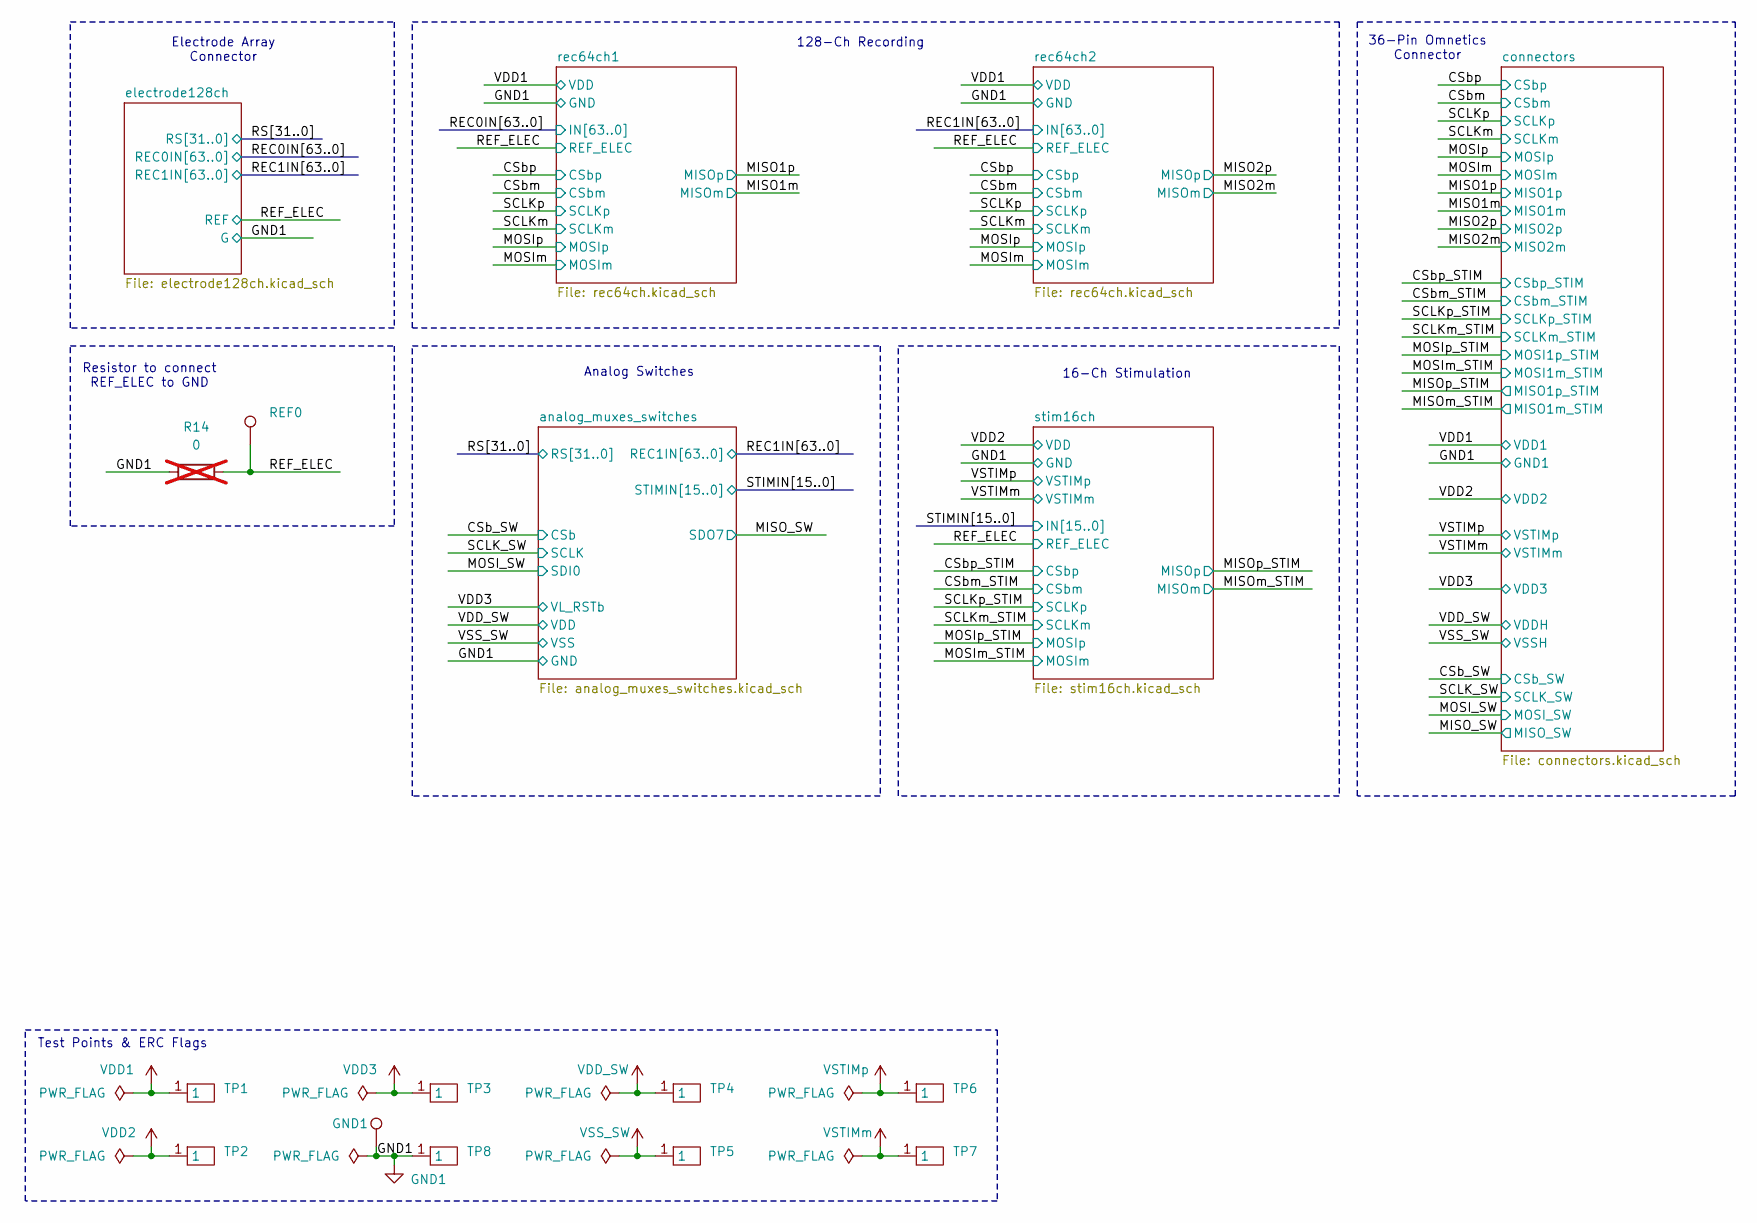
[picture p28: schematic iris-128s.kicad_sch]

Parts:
GND1: GND1; TESTPOINT_SMALL
R14: 0; R_0402_1005Metric; not fitted
REF0: REF0; TESTPOINT_SMALL
TP1, TP2, TP3, TP4, TP5, TP6, TP7, TP8: TESTPOINT_PAD_SQ_0.5

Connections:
/REF_ELEC: R14.2, REF0.1; also elsewhere on the board
GND1: GND1.1, R14.1, TP8.1; also elsewhere on the board
VDD1: TP1.1; also elsewhere on the board
VDD2: TP2.1; also elsewhere on the board
VDD3: TP3.1; also elsewhere on the board
VDD_SW: TP4.1; also elsewhere on the board
VSS_SW: TP5.1; also elsewhere on the board
VSTIMm: TP7.1; also elsewhere on the board
VSTIMp: TP6.1; also elsewhere on the board

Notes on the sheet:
Resistor to connect REF_ELEC to GND
Analog Switches
16-Ch Stimulation
128-Ch Recording
Electrode Array Connector
Test Points & ERC Flags
36-Pin Omnetics Connector

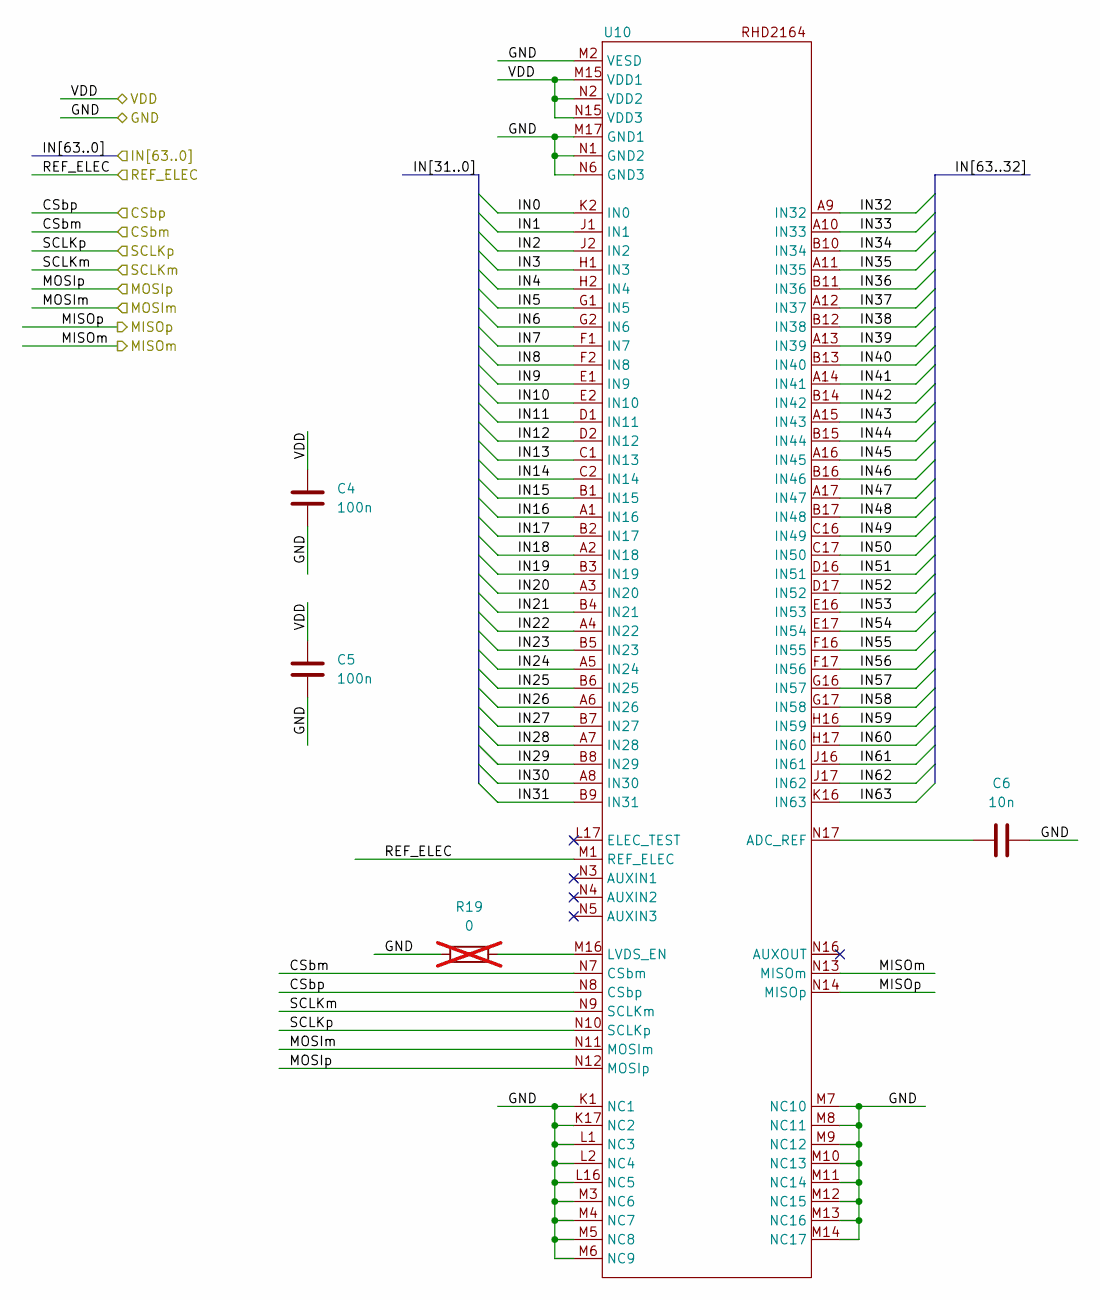
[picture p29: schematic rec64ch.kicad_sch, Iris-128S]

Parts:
C4, C5: 100n; C_0201_0603Metric; MPN C0603X5R1C104K030BC
C6: 10n; C_0201_0603Metric; MPN GRM033R61C103KA12D
R19: 0; R_0201_0603Metric; MPN RC0201FR-070RL; not fitted
U10: 104-Pin BGA - 9mmx7mm; MPN RHD2164

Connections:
/CSbm: U10.N7 (CSbm); also elsewhere on the board
/CSbp: U10.N8 (CSbp); also elsewhere on the board
/MISO2m: U10.N13 (MISOm); also elsewhere on the board
/MISO2p: U10.N14 (MISOp); also elsewhere on the board
/MOSIm: U10.N11 (MOSIm); also elsewhere on the board
/MOSIp: U10.N12 (MOSIp); also elsewhere on the board
/REC1IN0: U10.K2 (IN0); also elsewhere on the board
/REC1IN1: U10.J1 (IN1); also elsewhere on the board
/REC1IN2: U10.J2 (IN2); also elsewhere on the board
/REC1IN3: U10.H1 (IN3); also elsewhere on the board
/REC1IN4: U10.H2 (IN4); also elsewhere on the board
/REC1IN5: U10.G1 (IN5); also elsewhere on the board
/REC1IN6: U10.G2 (IN6); also elsewhere on the board
/REC1IN7: U10.F1 (IN7); also elsewhere on the board
/REC1IN8: U10.F2 (IN8); also elsewhere on the board
/REC1IN9: U10.E1 (IN9); also elsewhere on the board
/REC1IN10: U10.E2 (IN10); also elsewhere on the board
/REC1IN11: U10.D1 (IN11); also elsewhere on the board
/REC1IN12: U10.D2 (IN12); also elsewhere on the board
/REC1IN13: U10.C1 (IN13); also elsewhere on the board
/REC1IN14: U10.C2 (IN14); also elsewhere on the board
/REC1IN15: U10.B1 (IN15); also elsewhere on the board
/REC1IN16: U10.A1 (IN16); also elsewhere on the board
/REC1IN17: U10.B2 (IN17); also elsewhere on the board
/REC1IN18: U10.A2 (IN18); also elsewhere on the board
/REC1IN19: U10.B3 (IN19); also elsewhere on the board
/REC1IN20: U10.A3 (IN20); also elsewhere on the board
/REC1IN21: U10.B4 (IN21); also elsewhere on the board
/REC1IN22: U10.A4 (IN22); also elsewhere on the board
/REC1IN23: U10.B5 (IN23); also elsewhere on the board
/REC1IN24: U10.A5 (IN24); also elsewhere on the board
/REC1IN25: U10.B6 (IN25); also elsewhere on the board
/REC1IN26: U10.A6 (IN26); also elsewhere on the board
/REC1IN27: U10.B7 (IN27); also elsewhere on the board
/REC1IN28: U10.A7 (IN28); also elsewhere on the board
/REC1IN29: U10.B8 (IN29); also elsewhere on the board
/REC1IN30: U10.A8 (IN30); also elsewhere on the board
/REC1IN31: U10.B9 (IN31); also elsewhere on the board
/REC1IN32: U10.A9 (IN32); also elsewhere on the board
/REC1IN33: U10.A10 (IN33); also elsewhere on the board
/REC1IN34: U10.B10 (IN34); also elsewhere on the board
/REC1IN35: U10.A11 (IN35); also elsewhere on the board
/REC1IN36: U10.B11 (IN36); also elsewhere on the board
/REC1IN37: U10.A12 (IN37); also elsewhere on the board
/REC1IN38: U10.B12 (IN38); also elsewhere on the board
/REC1IN39: U10.A13 (IN39); also elsewhere on the board
/REC1IN40: U10.B13 (IN40); also elsewhere on the board
/REC1IN41: U10.A14 (IN41); also elsewhere on the board
/REC1IN42: U10.B14 (IN42); also elsewhere on the board
/REC1IN43: U10.A15 (IN43); also elsewhere on the board
/REC1IN44: U10.B15 (IN44); also elsewhere on the board
/REC1IN45: U10.A16 (IN45); also elsewhere on the board
/REC1IN46: U10.B16 (IN46); also elsewhere on the board
/REC1IN47: U10.A17 (IN47); also elsewhere on the board
/REC1IN48: U10.B17 (IN48); also elsewhere on the board
/REC1IN49: U10.C16 (IN49); also elsewhere on the board
/REC1IN50: U10.C17 (IN50); also elsewhere on the board
/REC1IN51: U10.D16 (IN51); also elsewhere on the board
/REC1IN52: U10.D17 (IN52); also elsewhere on the board
/REC1IN53: U10.E16 (IN53); also elsewhere on the board
/REC1IN54: U10.E17 (IN54); also elsewhere on the board
/REC1IN55: U10.F16 (IN55); also elsewhere on the board
/REC1IN56: U10.F17 (IN56); also elsewhere on the board
/REC1IN57: U10.G16 (IN57); also elsewhere on the board
/REC1IN58: U10.G17 (IN58); also elsewhere on the board
/REC1IN59: U10.H16 (IN59); also elsewhere on the board
/REC1IN60: U10.H17 (IN60); also elsewhere on the board
/REC1IN61: U10.J16 (IN61); also elsewhere on the board
/REC1IN62: U10.J17 (IN62); also elsewhere on the board
/REC1IN63: U10.K16 (IN63); also elsewhere on the board
/REF_ELEC: U10.M1 (REF_ELEC); also elsewhere on the board
/SCLKm: U10.N9 (SCLKm); also elsewhere on the board
/SCLKp: U10.N10 (SCLKp); also elsewhere on the board
GND1: C4.2, C5.2, C6.2, R19.1, U10.K1 (NC1), U10.K17 (NC2), U10.L1 (NC3), U10.L2 (NC4), U10.L16 (NC5), U10.M2 (VESD), U10.M3 (NC6), U10.M4 (NC7), U10.M5 (NC8), U10.M6 (NC9), U10.M7 (NC10), U10.M8 (NC11), U10.M9 (NC12), U10.M10 (NC13), U10.M11 (NC14), U10.M12 (NC15), U10.M13 (NC16), U10.M14 (NC17), U10.M17 (GND1), U10.N1 (GND2), U10.N6 (GND3); also elsewhere on the board
unnamed: C6.1, U10.N17 (ADC_REF)
unnamed: R19.2, U10.M16 (LVDS_EN)
VDD1: C4.1, C5.1, U10.M15 (VDD1), U10.N2 (VDD2), U10.N15 (VDD3); also elsewhere on the board

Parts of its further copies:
C1, C2: 100n; C_0201_0603Metric; MPN C0603X5R1C104K030BC
C3: 10n; C_0201_0603Metric; MPN GRM033R61C103KA12D
R10: 0; R_0201_0603Metric; MPN RC0201FR-070RL; not fitted
U9: 104-Pin BGA - 9mmx7mm; MPN RHD2164

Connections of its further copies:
/CSbm: U9.N7 (CSbm); also elsewhere on the board
/CSbp: U9.N8 (CSbp); also elsewhere on the board
/MISO1m: U9.N13 (MISOm); also elsewhere on the board
/MISO1p: U9.N14 (MISOp); also elsewhere on the board
/MOSIm: U9.N11 (MOSIm); also elsewhere on the board
/MOSIp: U9.N12 (MOSIp); also elsewhere on the board
/REC0IN0: U9.K2 (IN0); also elsewhere on the board
/REC0IN1: U9.J1 (IN1); also elsewhere on the board
/REC0IN2: U9.J2 (IN2); also elsewhere on the board
/REC0IN3: U9.H1 (IN3); also elsewhere on the board
/REC0IN4: U9.H2 (IN4); also elsewhere on the board
/REC0IN5: U9.G1 (IN5); also elsewhere on the board
/REC0IN6: U9.G2 (IN6); also elsewhere on the board
/REC0IN7: U9.F1 (IN7); also elsewhere on the board
/REC0IN8: U9.F2 (IN8); also elsewhere on the board
/REC0IN9: U9.E1 (IN9); also elsewhere on the board
/REC0IN10: U9.E2 (IN10); also elsewhere on the board
/REC0IN11: U9.D1 (IN11); also elsewhere on the board
/REC0IN12: U9.D2 (IN12); also elsewhere on the board
/REC0IN13: U9.C1 (IN13); also elsewhere on the board
/REC0IN14: U9.C2 (IN14); also elsewhere on the board
/REC0IN15: U9.B1 (IN15); also elsewhere on the board
/REC0IN16: U9.A1 (IN16); also elsewhere on the board
/REC0IN17: U9.B2 (IN17); also elsewhere on the board
/REC0IN18: U9.A2 (IN18); also elsewhere on the board
/REC0IN19: U9.B3 (IN19); also elsewhere on the board
/REC0IN20: U9.A3 (IN20); also elsewhere on the board
/REC0IN21: U9.B4 (IN21); also elsewhere on the board
/REC0IN22: U9.A4 (IN22); also elsewhere on the board
/REC0IN23: U9.B5 (IN23); also elsewhere on the board
/REC0IN24: U9.A5 (IN24); also elsewhere on the board
/REC0IN25: U9.B6 (IN25); also elsewhere on the board
/REC0IN26: U9.A6 (IN26); also elsewhere on the board
/REC0IN27: U9.B7 (IN27); also elsewhere on the board
/REC0IN28: U9.A7 (IN28); also elsewhere on the board
/REC0IN29: U9.B8 (IN29); also elsewhere on the board
/REC0IN30: U9.A8 (IN30); also elsewhere on the board
/REC0IN31: U9.B9 (IN31); also elsewhere on the board
/REC0IN32: U9.A9 (IN32); also elsewhere on the board
/REC0IN33: U9.A10 (IN33); also elsewhere on the board
/REC0IN34: U9.B10 (IN34); also elsewhere on the board
/REC0IN35: U9.A11 (IN35); also elsewhere on the board
/REC0IN36: U9.B11 (IN36); also elsewhere on the board
/REC0IN37: U9.A12 (IN37); also elsewhere on the board
/REC0IN38: U9.B12 (IN38); also elsewhere on the board
/REC0IN39: U9.A13 (IN39); also elsewhere on the board
/REC0IN40: U9.B13 (IN40); also elsewhere on the board
/REC0IN41: U9.A14 (IN41); also elsewhere on the board
/REC0IN42: U9.B14 (IN42); also elsewhere on the board
/REC0IN43: U9.A15 (IN43); also elsewhere on the board
/REC0IN44: U9.B15 (IN44); also elsewhere on the board
/REC0IN45: U9.A16 (IN45); also elsewhere on the board
/REC0IN46: U9.B16 (IN46); also elsewhere on the board
/REC0IN47: U9.A17 (IN47); also elsewhere on the board
/REC0IN48: U9.B17 (IN48); also elsewhere on the board
/REC0IN49: U9.C16 (IN49); also elsewhere on the board
/REC0IN50: U9.C17 (IN50); also elsewhere on the board
/REC0IN51: U9.D16 (IN51); also elsewhere on the board
/REC0IN52: U9.D17 (IN52); also elsewhere on the board
/REC0IN53: U9.E16 (IN53); also elsewhere on the board
/REC0IN54: U9.E17 (IN54); also elsewhere on the board
/REC0IN55: U9.F16 (IN55); also elsewhere on the board
/REC0IN56: U9.F17 (IN56); also elsewhere on the board
/REC0IN57: U9.G16 (IN57); also elsewhere on the board
/REC0IN58: U9.G17 (IN58); also elsewhere on the board
/REC0IN59: U9.H16 (IN59); also elsewhere on the board
/REC0IN60: U9.H17 (IN60); also elsewhere on the board
/REC0IN61: U9.J16 (IN61); also elsewhere on the board
/REC0IN62: U9.J17 (IN62); also elsewhere on the board
/REC0IN63: U9.K16 (IN63); also elsewhere on the board
/REF_ELEC: U9.M1 (REF_ELEC); also elsewhere on the board
/SCLKm: U9.N9 (SCLKm); also elsewhere on the board
/SCLKp: U9.N10 (SCLKp); also elsewhere on the board
GND1: C1.2, C2.2, C3.2, R10.1, U9.K1 (NC1), U9.K17 (NC2), U9.L1 (NC3), U9.L2 (NC4), U9.L16 (NC5), U9.M2 (VESD), U9.M3 (NC6), U9.M4 (NC7), U9.M5 (NC8), U9.M6 (NC9), U9.M7 (NC10), U9.M8 (NC11), U9.M9 (NC12), U9.M10 (NC13), U9.M11 (NC14), U9.M12 (NC15), U9.M13 (NC16), U9.M14 (NC17), U9.M17 (GND1), U9.N1 (GND2), U9.N6 (GND3); also elsewhere on the board
unnamed: C3.1, U9.N17 (ADC_REF)
unnamed: R10.2, U9.M16 (LVDS_EN)
VDD1: C1.1, C2.1, U9.M15 (VDD1), U9.N2 (VDD2), U9.N15 (VDD3); also elsewhere on the board

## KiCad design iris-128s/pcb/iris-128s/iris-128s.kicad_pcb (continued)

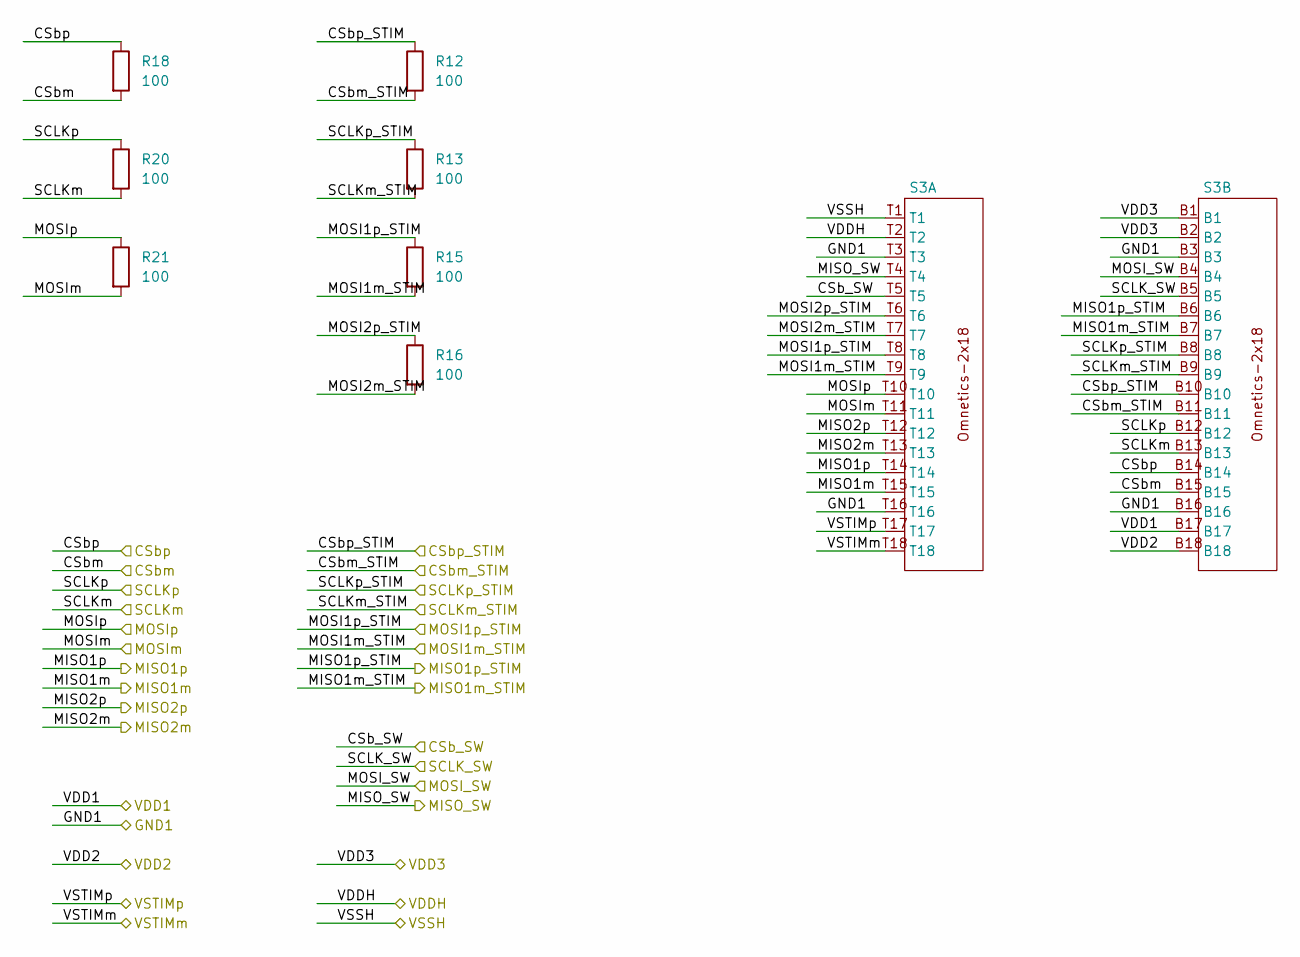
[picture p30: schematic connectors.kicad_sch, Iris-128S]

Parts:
R12, R13, R15, R16, R18, R20, R21: 100; R_0201_0603Metric; MPN RC0201FR-07100RL
S3: OMNETICS-A79024-001; MPN A79024-001

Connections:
/CSb_SW: S3.T5; also elsewhere on the board
/CSbm: R18.2, S3.B15; also elsewhere on the board
/CSbm_STIM: R12.2, S3.B11; also elsewhere on the board
/CSbp: R18.1, S3.B14; also elsewhere on the board
/CSbp_STIM: R12.1, S3.B10; also elsewhere on the board
/MISO1m: S3.T15; also elsewhere on the board
/MISO1p: S3.T14; also elsewhere on the board
/MISO2m: S3.T13; also elsewhere on the board
/MISO2p: S3.T12; also elsewhere on the board
/MISO_SW: S3.T4; also elsewhere on the board
/MISOm_STIM: S3.B7; also elsewhere on the board
/MISOp_STIM: S3.B6; also elsewhere on the board
/MOSI_SW: S3.B4; also elsewhere on the board
/MOSIm: R21.2, S3.T11; also elsewhere on the board
/MOSIm_STIM: R15.2, S3.T9; also elsewhere on the board
/MOSIp: R21.1, S3.T10; also elsewhere on the board
/MOSIp_STIM: R15.1, S3.T8; also elsewhere on the board
/SCLK_SW: S3.B5; also elsewhere on the board
/SCLKm: R20.2, S3.B13; also elsewhere on the board
/SCLKm_STIM: R13.2, S3.B9; also elsewhere on the board
/SCLKp: R20.1, S3.B12; also elsewhere on the board
/SCLKp_STIM: R13.1, S3.B8; also elsewhere on the board
/connectors/MOSI2m_STIM: R16.2, S3.T7
/connectors/MOSI2p_STIM: R16.1, S3.T6
GND1: S3.B3, S3.B16, S3.T3, S3.T16; also elsewhere on the board
VDD1: S3.B17; also elsewhere on the board
VDD2: S3.B18; also elsewhere on the board
VDD3: S3.B1, S3.B2; also elsewhere on the board
VDD_SW: S3.T2; also elsewhere on the board
VSS_SW: S3.T1; also elsewhere on the board
VSTIMm: S3.T18; also elsewhere on the board
VSTIMp: S3.T17; also elsewhere on the board

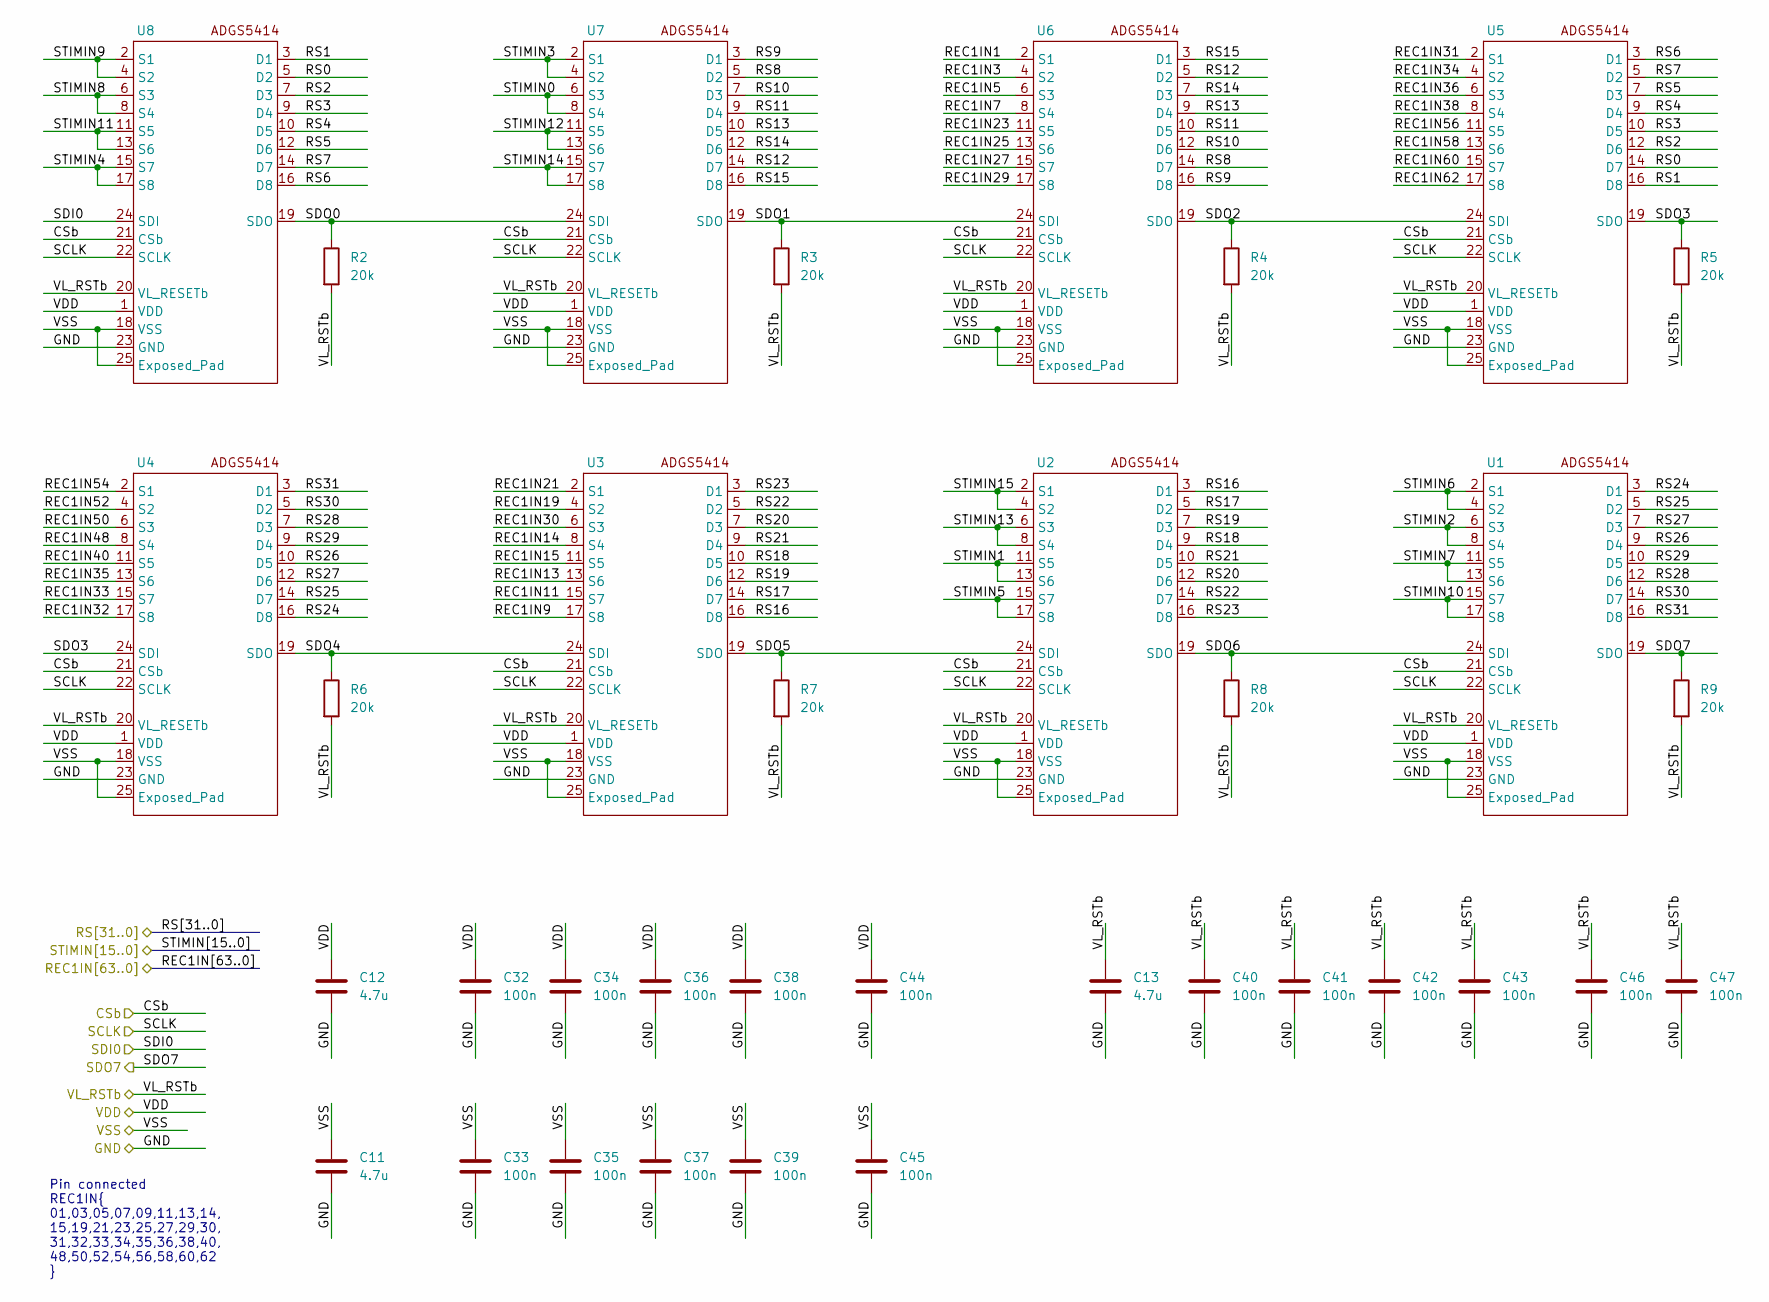
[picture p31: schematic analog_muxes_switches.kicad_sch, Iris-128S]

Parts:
C11, C12, C13: 4.7u; C_0402_1005Metric; MPN KGM05CR51C475MH
C32, C33, C34, C35, C36, C37, C38, C39, C40, C41, C42, C43, C44, C45, C46, C47: 100n; C_0201_0603Metric; MPN C0603X5R1C104K030BC
R2, R3, R4, R5, R6, R7, R8, R9: 20k; R_0201_0603Metric; MPN RC0201FR-0720KL
U1, U2, U3, U4, U5, U6, U7, U8: LFCSP-24-1EP_4mmx4mm_P0.5mm_EP2.6mm; MPN ADGS5414BCPZ

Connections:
/CSb_SW: U1.21 (CSb), U2.21 (CSb), U3.21 (CSb), U4.21 (CSb), U5.21 (CSb), U6.21 (CSb), U7.21 (CSb), U8.21 (CSb); also elsewhere on the board
/MISO_SW: R9.1, U1.19 (SDO); also elsewhere on the board
/MOSI_SW: U8.24 (SDI); also elsewhere on the board
/REC1IN1: U6.2 (S1); also elsewhere on the board
/REC1IN3: U6.4 (S2); also elsewhere on the board
/REC1IN5: U6.6 (S3); also elsewhere on the board
/REC1IN7: U6.8 (S4); also elsewhere on the board
/REC1IN9: U3.17 (S8); also elsewhere on the board
/REC1IN11: U3.15 (S7); also elsewhere on the board
/REC1IN13: U3.13 (S6); also elsewhere on the board
/REC1IN14: U3.8 (S4); also elsewhere on the board
/REC1IN15: U3.11 (S5); also elsewhere on the board
/REC1IN19: U3.4 (S2); also elsewhere on the board
/REC1IN21: U3.2 (S1); also elsewhere on the board
/REC1IN23: U6.11 (S5); also elsewhere on the board
/REC1IN25: U6.13 (S6); also elsewhere on the board
/REC1IN27: U6.15 (S7); also elsewhere on the board
/REC1IN29: U6.17 (S8); also elsewhere on the board
/REC1IN30: U3.6 (S3); also elsewhere on the board
/REC1IN31: U5.2 (S1); also elsewhere on the board
/REC1IN32: U4.17 (S8); also elsewhere on the board
/REC1IN33: U4.15 (S7); also elsewhere on the board
/REC1IN34: U5.4 (S2); also elsewhere on the board
/REC1IN35: U4.13 (S6); also elsewhere on the board
/REC1IN36: U5.6 (S3); also elsewhere on the board
/REC1IN38: U5.8 (S4); also elsewhere on the board
/REC1IN40: U4.11 (S5); also elsewhere on the board
/REC1IN48: U4.8 (S4); also elsewhere on the board
/REC1IN50: U4.6 (S3); also elsewhere on the board
/REC1IN52: U4.4 (S2); also elsewhere on the board
/REC1IN54: U4.2 (S1); also elsewhere on the board
/REC1IN56: U5.11 (S5); also elsewhere on the board
/REC1IN58: U5.13 (S6); also elsewhere on the board
/REC1IN60: U5.15 (S7); also elsewhere on the board
/REC1IN62: U5.17 (S8); also elsewhere on the board
/RS0: U5.14 (D7), U8.5 (D2); also elsewhere on the board
/RS1: U5.16 (D8), U8.3 (D1); also elsewhere on the board
/RS2: U5.12 (D6), U8.7 (D3); also elsewhere on the board
/RS3: U5.10 (D5), U8.9 (D4); also elsewhere on the board
/RS4: U5.9 (D4), U8.10 (D5); also elsewhere on the board
/RS5: U5.7 (D3), U8.12 (D6); also elsewhere on the board
/RS6: U5.3 (D1), U8.16 (D8); also elsewhere on the board
/RS7: U5.5 (D2), U8.14 (D7); also elsewhere on the board
/RS8: U6.14 (D7), U7.5 (D2); also elsewhere on the board
/RS9: U6.16 (D8), U7.3 (D1); also elsewhere on the board
/RS10: U6.12 (D6), U7.7 (D3); also elsewhere on the board
/RS11: U6.10 (D5), U7.9 (D4); also elsewhere on the board
/RS12: U6.5 (D2), U7.14 (D7); also elsewhere on the board
/RS13: U6.9 (D4), U7.10 (D5); also elsewhere on the board
/RS14: U6.7 (D3), U7.12 (D6); also elsewhere on the board
/RS15: U6.3 (D1), U7.16 (D8); also elsewhere on the board
/RS16: U2.3 (D1), U3.16 (D8); also elsewhere on the board
/RS17: U2.5 (D2), U3.14 (D7); also elsewhere on the board
/RS18: U2.9 (D4), U3.10 (D5); also elsewhere on the board
/RS19: U2.7 (D3), U3.12 (D6); also elsewhere on the board
/RS20: U2.12 (D6), U3.7 (D3); also elsewhere on the board
/RS21: U2.10 (D5), U3.9 (D4); also elsewhere on the board
/RS22: U2.14 (D7), U3.5 (D2); also elsewhere on the board
/RS23: U2.16 (D8), U3.3 (D1); also elsewhere on the board
/RS24: U1.3 (D1), U4.16 (D8); also elsewhere on the board
/RS25: U1.5 (D2), U4.14 (D7); also elsewhere on the board
/RS26: U1.9 (D4), U4.10 (D5); also elsewhere on the board
/RS27: U1.7 (D3), U4.12 (D6); also elsewhere on the board
/RS28: U1.12 (D6), U4.7 (D3); also elsewhere on the board
/RS29: U1.10 (D5), U4.9 (D4); also elsewhere on the board
/RS30: U1.14 (D7), U4.5 (D2); also elsewhere on the board
/RS31: U1.16 (D8), U4.3 (D1); also elsewhere on the board
/SCLK_SW: U1.22 (SCLK), U2.22 (SCLK), U3.22 (SCLK), U4.22 (SCLK), U5.22 (SCLK), U6.22 (SCLK), U7.22 (SCLK), U8.22 (SCLK); also elsewhere on the board
/STIMIN0: U7.6 (S3), U7.8 (S4); also elsewhere on the board
/STIMIN1: U2.11 (S5), U2.13 (S6); also elsewhere on the board
/STIMIN2: U1.6 (S3), U1.8 (S4); also elsewhere on the board
/STIMIN3: U7.2 (S1), U7.4 (S2); also elsewhere on the board
/STIMIN4: U8.15 (S7), U8.17 (S8); also elsewhere on the board
/STIMIN5: U2.15 (S7), U2.17 (S8); also elsewhere on the board
/STIMIN6: U1.2 (S1), U1.4 (S2); also elsewhere on the board
/STIMIN7: U1.11 (S5), U1.13 (S6); also elsewhere on the board
/STIMIN8: U8.6 (S3), U8.8 (S4); also elsewhere on the board
/STIMIN9: U8.2 (S1), U8.4 (S2); also elsewhere on the board
/STIMIN10: U1.15 (S7), U1.17 (S8); also elsewhere on the board
/STIMIN11: U8.11 (S5), U8.13 (S6); also elsewhere on the board
/STIMIN12: U7.11 (S5), U7.13 (S6); also elsewhere on the board
/STIMIN13: U2.6 (S3), U2.8 (S4); also elsewhere on the board
/STIMIN14: U7.15 (S7), U7.17 (S8); also elsewhere on the board
/STIMIN15: U2.2 (S1), U2.4 (S2); also elsewhere on the board
/analog_muxes_switches/SDO0: R2.1, U7.24 (SDI), U8.19 (SDO)
/analog_muxes_switches/SDO1: R3.1, U6.24 (SDI), U7.19 (SDO)
/analog_muxes_switches/SDO2: R4.1, U5.24 (SDI), U6.19 (SDO)
/analog_muxes_switches/SDO3: R5.1, U4.24 (SDI), U5.19 (SDO)
/analog_muxes_switches/SDO4: R6.1, U3.24 (SDI), U4.19 (SDO)
/analog_muxes_switches/SDO5: R7.1, U2.24 (SDI), U3.19 (SDO)
/analog_muxes_switches/SDO6: R8.1, U1.24 (SDI), U2.19 (SDO)
GND1: C11.2, C12.2, C13.2, C32.2, C33.2, C34.2, C35.2, C36.2, C37.2, C38.2, C39.2, C40.2, C41.2, C42.2, C43.2, C44.2, C45.2, C46.2, C47.2, U1.23 (GND), U2.23 (GND), U3.23 (GND), U4.23 (GND), U5.23 (GND), U6.23 (GND), U7.23 (GND), U8.23 (GND); also elsewhere on the board
VDD3: C13.1, C40.1, C41.1, C42.1, C43.1, C46.1, C47.1, R2.2, R3.2, R4.2, R5.2, R6.2, R7.2, R8.2, R9.2, U1.20 (VL_RESETb), U2.20 (VL_RESETb), U3.20 (VL_RESETb), U4.20 (VL_RESETb), U5.20 (VL_RESETb), U6.20 (VL_RESETb), U7.20 (VL_RESETb), U8.20 (VL_RESETb); also elsewhere on the board
VDD_SW: C12.1, C32.1, C34.1, C36.1, C38.1, C44.1, U1.1 (VDD), U2.1 (VDD), U3.1 (VDD), U4.1 (VDD), U5.1 (VDD), U6.1 (VDD), U7.1 (VDD), U8.1 (VDD); also elsewhere on the board
VSS_SW: C11.1, C33.1, C35.1, C37.1, C39.1, C45.1, U1.18 (VSS), U1.25 (Exposed_Pad), U2.18 (VSS), U2.25 (Exposed_Pad), U3.18 (VSS), U3.25 (Exposed_Pad), U4.18 (VSS), U4.25 (Exposed_Pad), U5.18 (VSS), U5.25 (Exposed_Pad), U6.18 (VSS), U6.25 (Exposed_Pad), U7.18 (VSS), U7.25 (Exposed_Pad), U8.18 (VSS), U8.25 (Exposed_Pad); also elsewhere on the board

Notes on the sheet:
Pin connected REC1IN{ 01,03,05,07,09,11,13,14, 15,19,21,23,25,27,29,30, 31,32,33,34,35,36,38,40, 48,50,52,54,56,58,60,62 }

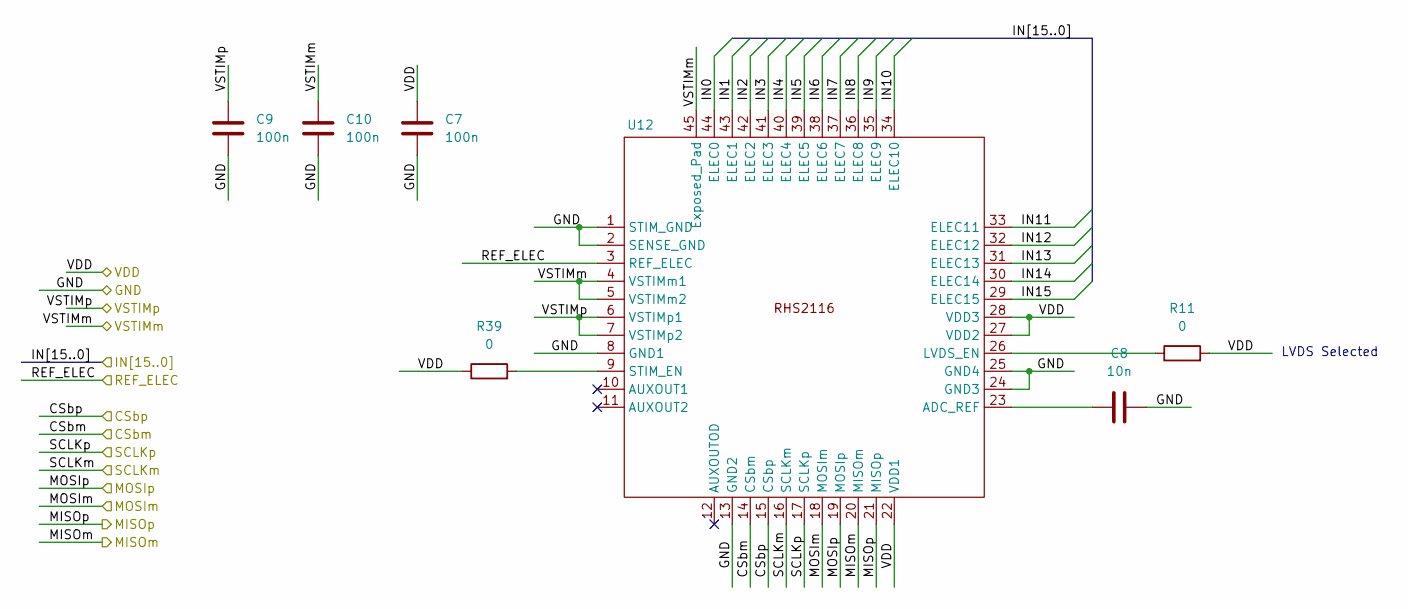
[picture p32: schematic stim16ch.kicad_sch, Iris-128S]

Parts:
C7, C9, C10: 100n; C_0201_0603Metric; MPN C0603X5R1C104K030BC
C8: 10n; C_0201_0603Metric; MPN GRM033R61C103KA12D
R11, R39: 0; R_0201_0603Metric; MPN RC0201FR-070RL
U12: QFN-44-1EP_7x7mm_P0.5mm_EP5.4x5.4mm; MPN RHS2116

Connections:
/CSbm_STIM: U12.14 (CSbm); also elsewhere on the board
/CSbp_STIM: U12.15 (CSbp); also elsewhere on the board
/MISOm_STIM: U12.20 (MISOm); also elsewhere on the board
/MISOp_STIM: U12.21 (MISOp); also elsewhere on the board
/MOSIm_STIM: U12.18 (MOSIm); also elsewhere on the board
/MOSIp_STIM: U12.19 (MOSIp); also elsewhere on the board
/REF_ELEC: U12.3 (REF_ELEC); also elsewhere on the board
/SCLKm_STIM: U12.16 (SCLKm); also elsewhere on the board
/SCLKp_STIM: U12.17 (SCLKp); also elsewhere on the board
/STIMIN0: U12.44 (ELEC0); also elsewhere on the board
/STIMIN1: U12.43 (ELEC1); also elsewhere on the board
/STIMIN2: U12.42 (ELEC2); also elsewhere on the board
/STIMIN3: U12.41 (ELEC3); also elsewhere on the board
/STIMIN4: U12.40 (ELEC4); also elsewhere on the board
/STIMIN5: U12.39 (ELEC5); also elsewhere on the board
/STIMIN6: U12.38 (ELEC6); also elsewhere on the board
/STIMIN7: U12.37 (ELEC7); also elsewhere on the board
/STIMIN8: U12.36 (ELEC8); also elsewhere on the board
/STIMIN9: U12.35 (ELEC9); also elsewhere on the board
/STIMIN10: U12.34 (ELEC10); also elsewhere on the board
/STIMIN11: U12.33 (ELEC11); also elsewhere on the board
/STIMIN12: U12.32 (ELEC12); also elsewhere on the board
/STIMIN13: U12.31 (ELEC13); also elsewhere on the board
/STIMIN14: U12.30 (ELEC14); also elsewhere on the board
/STIMIN15: U12.29 (ELEC15); also elsewhere on the board
GND1: C7.2, C8.2, C9.2, C10.2, U12.1 (STIM_GND), U12.2 (SENSE_GND), U12.8 (GND1), U12.13 (GND2), U12.24 (GND3), U12.25 (GND4); also elsewhere on the board
unnamed: C8.1, U12.23 (ADC_REF)
unnamed: R11.1, U12.26 (LVDS_EN)
unnamed: R39.2, U12.9 (STIM_EN)
VDD2: C7.1, R11.2, R39.1, U12.22 (VDD1), U12.27 (VDD2), U12.28 (VDD3); also elsewhere on the board
VSTIMm: C10.1, U12.4 (VSTIMm1), U12.5 (VSTIMm2), U12.45 (Exposed_Pad); also elsewhere on the board
VSTIMp: C9.1, U12.6 (VSTIMp1), U12.7 (VSTIMp2); also elsewhere on the board

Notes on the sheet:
LVDS Selected

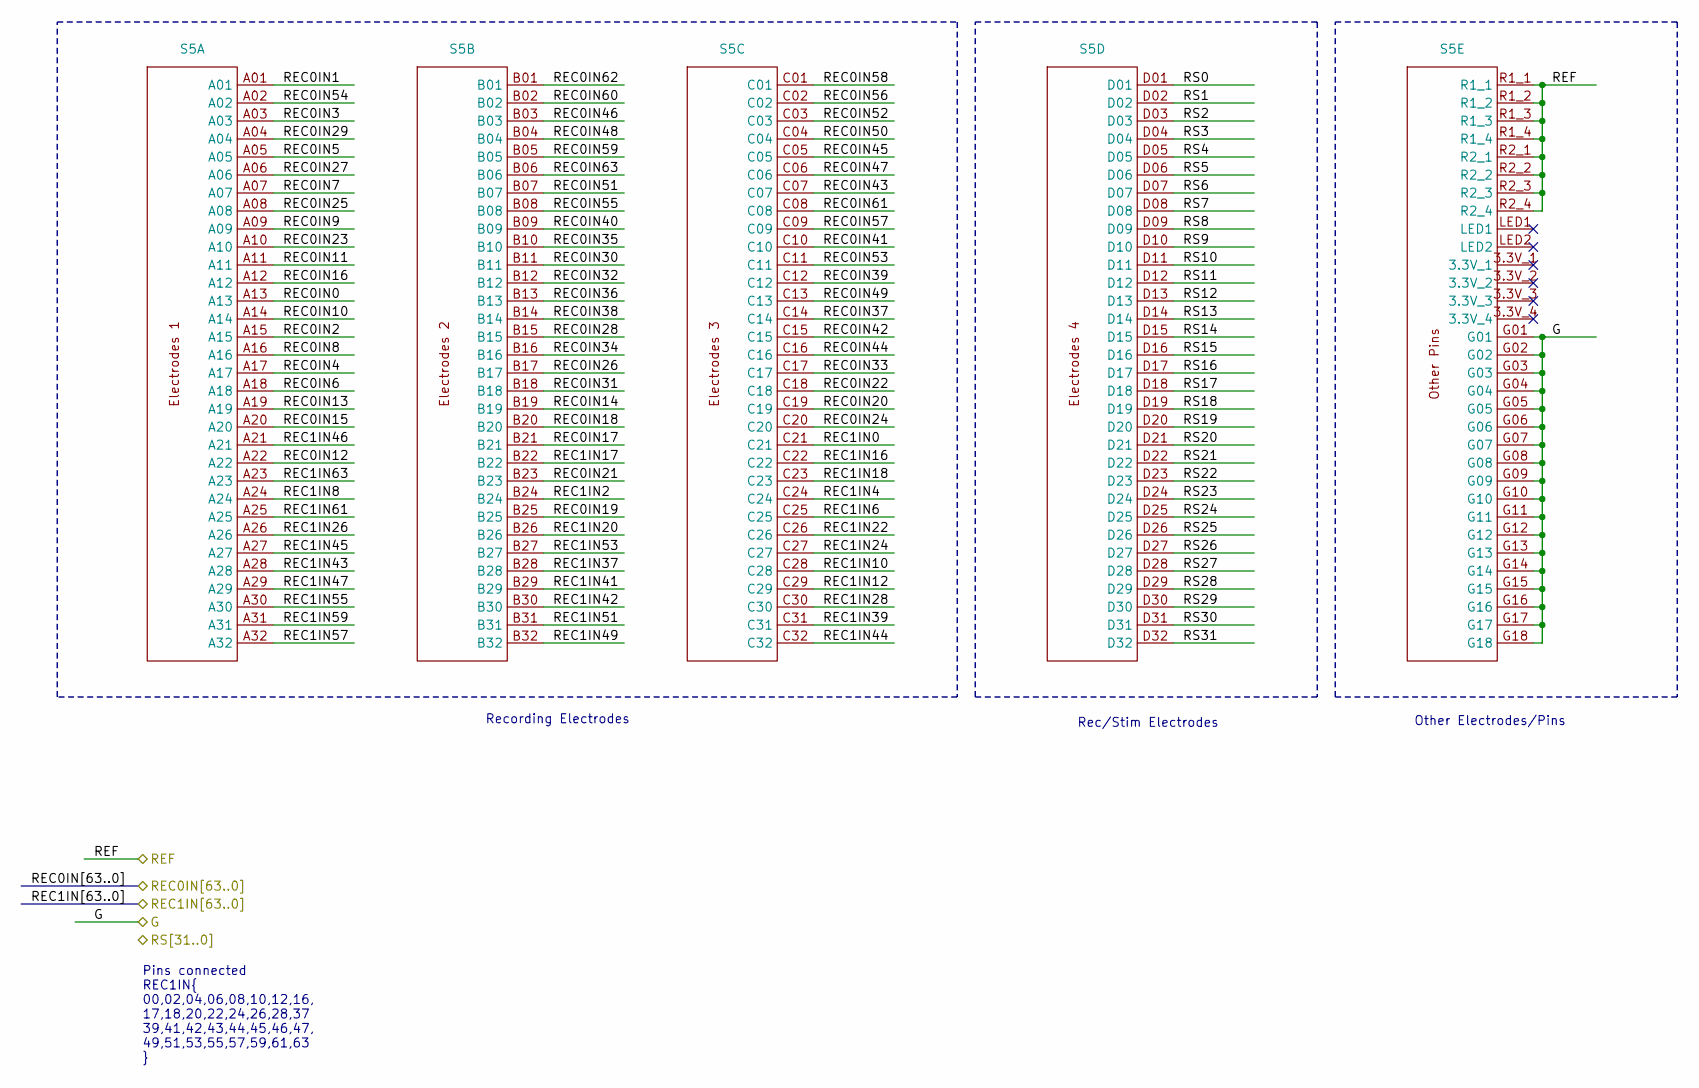
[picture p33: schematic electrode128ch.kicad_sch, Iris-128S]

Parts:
S5: SAMTEC_SEAM8-20-S02.0-X-08-3_Cereplex; MPN SEAM8-20-S02.0-S-08-3

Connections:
/REC0IN0: S5.A13; also elsewhere on the board
/REC0IN1: S5.A01; also elsewhere on the board
/REC0IN2: S5.A15; also elsewhere on the board
/REC0IN3: S5.A03; also elsewhere on the board
/REC0IN4: S5.A17; also elsewhere on the board
/REC0IN5: S5.A05; also elsewhere on the board
/REC0IN6: S5.A18; also elsewhere on the board
/REC0IN7: S5.A07; also elsewhere on the board
/REC0IN8: S5.A16; also elsewhere on the board
/REC0IN9: S5.A09; also elsewhere on the board
/REC0IN10: S5.A14; also elsewhere on the board
/REC0IN11: S5.A11; also elsewhere on the board
/REC0IN12: S5.A22; also elsewhere on the board
/REC0IN13: S5.A19; also elsewhere on the board
/REC0IN14: S5.B19; also elsewhere on the board
/REC0IN15: S5.A20; also elsewhere on the board
/REC0IN16: S5.A12; also elsewhere on the board
/REC0IN17: S5.B21; also elsewhere on the board
/REC0IN18: S5.B20; also elsewhere on the board
/REC0IN19: S5.B25; also elsewhere on the board
/REC0IN20: S5.C19; also elsewhere on the board
/REC0IN21: S5.B23; also elsewhere on the board
/REC0IN22: S5.C18; also elsewhere on the board
/REC0IN23: S5.A10; also elsewhere on the board
/REC0IN24: S5.C20; also elsewhere on the board
/REC0IN25: S5.A08; also elsewhere on the board
/REC0IN26: S5.B17; also elsewhere on the board
/REC0IN27: S5.A06; also elsewhere on the board
/REC0IN28: S5.B15; also elsewhere on the board
/REC0IN29: S5.A04; also elsewhere on the board
/REC0IN30: S5.B11; also elsewhere on the board
/REC0IN31: S5.B18; also elsewhere on the board
/REC0IN32: S5.B12; also elsewhere on the board
/REC0IN33: S5.C17; also elsewhere on the board
/REC0IN34: S5.B16; also elsewhere on the board
/REC0IN35: S5.B10; also elsewhere on the board
/REC0IN36: S5.B13; also elsewhere on the board
/REC0IN37: S5.C14; also elsewhere on the board
/REC0IN38: S5.B14; also elsewhere on the board
/REC0IN39: S5.C12; also elsewhere on the board
/REC0IN40: S5.B09; also elsewhere on the board
/REC0IN41: S5.C10; also elsewhere on the board
/REC0IN42: S5.C15; also elsewhere on the board
/REC0IN43: S5.C07; also elsewhere on the board
/REC0IN44: S5.C16; also elsewhere on the board
/REC0IN45: S5.C05; also elsewhere on the board
/REC0IN46: S5.B03; also elsewhere on the board
/REC0IN47: S5.C06; also elsewhere on the board
/REC0IN48: S5.B04; also elsewhere on the board
/REC0IN49: S5.C13; also elsewhere on the board
/REC0IN50: S5.C04; also elsewhere on the board
/REC0IN51: S5.B07; also elsewhere on the board
/REC0IN52: S5.C03; also elsewhere on the board
/REC0IN53: S5.C11; also elsewhere on the board
/REC0IN54: S5.A02; also elsewhere on the board
/REC0IN55: S5.B08; also elsewhere on the board
/REC0IN56: S5.C02; also elsewhere on the board
/REC0IN57: S5.C09; also elsewhere on the board
/REC0IN58: S5.C01; also elsewhere on the board
/REC0IN59: S5.B05; also elsewhere on the board
/REC0IN60: S5.B02; also elsewhere on the board
/REC0IN61: S5.C08; also elsewhere on the board
/REC0IN62: S5.B01; also elsewhere on the board
/REC0IN63: S5.B06; also elsewhere on the board
/REC1IN0: S5.C21; also elsewhere on the board
/REC1IN2: S5.B24; also elsewhere on the board
/REC1IN4: S5.C24; also elsewhere on the board
/REC1IN6: S5.C25; also elsewhere on the board
/REC1IN8: S5.A24; also elsewhere on the board
/REC1IN10: S5.C28; also elsewhere on the board
/REC1IN12: S5.C29; also elsewhere on the board
/REC1IN16: S5.C22; also elsewhere on the board
/REC1IN17: S5.B22; also elsewhere on the board
/REC1IN18: S5.C23; also elsewhere on the board
/REC1IN20: S5.B26; also elsewhere on the board
/REC1IN22: S5.C26; also elsewhere on the board
/REC1IN24: S5.C27; also elsewhere on the board
/REC1IN26: S5.A26; also elsewhere on the board
/REC1IN28: S5.C30; also elsewhere on the board
/REC1IN37: S5.B28; also elsewhere on the board
/REC1IN39: S5.C31; also elsewhere on the board
/REC1IN41: S5.B29; also elsewhere on the board
/REC1IN42: S5.B30; also elsewhere on the board
/REC1IN43: S5.A28; also elsewhere on the board
/REC1IN44: S5.C32; also elsewhere on the board
/REC1IN45: S5.A27; also elsewhere on the board
/REC1IN46: S5.A21; also elsewhere on the board
/REC1IN47: S5.A29; also elsewhere on the board
/REC1IN49: S5.B32; also elsewhere on the board
/REC1IN51: S5.B31; also elsewhere on the board
/REC1IN53: S5.B27; also elsewhere on the board
/REC1IN55: S5.A30; also elsewhere on the board
/REC1IN57: S5.A32; also elsewhere on the board
/REC1IN59: S5.A31; also elsewhere on the board
/REC1IN61: S5.A25; also elsewhere on the board
/REC1IN63: S5.A23; also elsewhere on the board
/REF_ELEC: S5.R1_1, S5.R1_2, S5.R1_3, S5.R1_4, S5.R2_1, S5.R2_2, S5.R2_3, S5.R2_4; also elsewhere on the board
/RS0: S5.D01; also elsewhere on the board
/RS1: S5.D02; also elsewhere on the board
/RS2: S5.D03; also elsewhere on the board
/RS3: S5.D04; also elsewhere on the board
/RS4: S5.D05; also elsewhere on the board
/RS5: S5.D06; also elsewhere on the board
/RS6: S5.D07; also elsewhere on the board
/RS7: S5.D08; also elsewhere on the board
/RS8: S5.D09; also elsewhere on the board
/RS9: S5.D10; also elsewhere on the board
/RS10: S5.D11; also elsewhere on the board
/RS11: S5.D12; also elsewhere on the board
/RS12: S5.D13; also elsewhere on the board
/RS13: S5.D14; also elsewhere on the board
/RS14: S5.D15; also elsewhere on the board
/RS15: S5.D16; also elsewhere on the board
/RS16: S5.D17; also elsewhere on the board
/RS17: S5.D18; also elsewhere on the board
/RS18: S5.D19; also elsewhere on the board
/RS19: S5.D20; also elsewhere on the board
/RS20: S5.D21; also elsewhere on the board
/RS21: S5.D22; also elsewhere on the board
/RS22: S5.D23; also elsewhere on the board
/RS23: S5.D24; also elsewhere on the board
/RS24: S5.D25; also elsewhere on the board
/RS25: S5.D26; also elsewhere on the board
/RS26: S5.D27; also elsewhere on the board
/RS27: S5.D28; also elsewhere on the board
/RS28: S5.D29; also elsewhere on the board
/RS29: S5.D30; also elsewhere on the board
/RS30: S5.D31; also elsewhere on the board
/RS31: S5.D32; also elsewhere on the board
GND1: S5.G01, S5.G02, S5.G03, S5.G04, S5.G05, S5.G06, S5.G07, S5.G08, S5.G09, S5.G10, S5.G11, S5.G12, S5.G13, S5.G14, S5.G15, S5.G16, S5.G17, S5.G18; also elsewhere on the board

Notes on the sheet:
Pins connected REC1IN{ 00,02,04,06,08,10,12,16, 17,18,20,22,24,26,28,37 39,41,42,43,44,45,46,47, 49,51,53,55,57,59,61,63 }
Rec/Stim Electrodes
Other Electrodes/Pins
Recording Electrodes

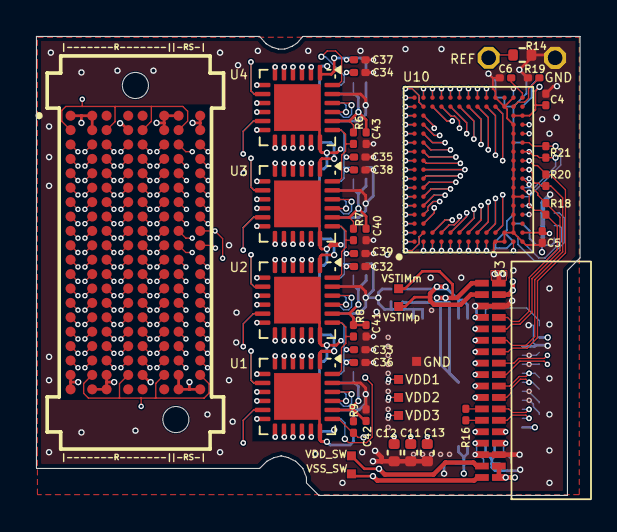
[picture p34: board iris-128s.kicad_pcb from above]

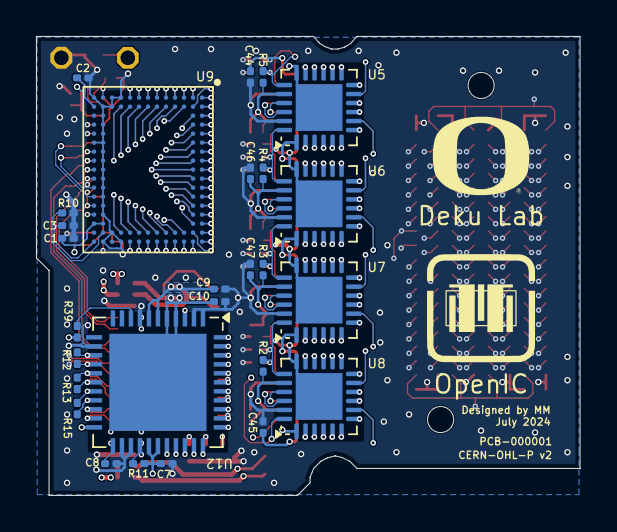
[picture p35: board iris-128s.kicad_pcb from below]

Board: 8 copper layers, 30.2 x 25.5 mm, 72 parts (27 on the bottom side), 223 nets.

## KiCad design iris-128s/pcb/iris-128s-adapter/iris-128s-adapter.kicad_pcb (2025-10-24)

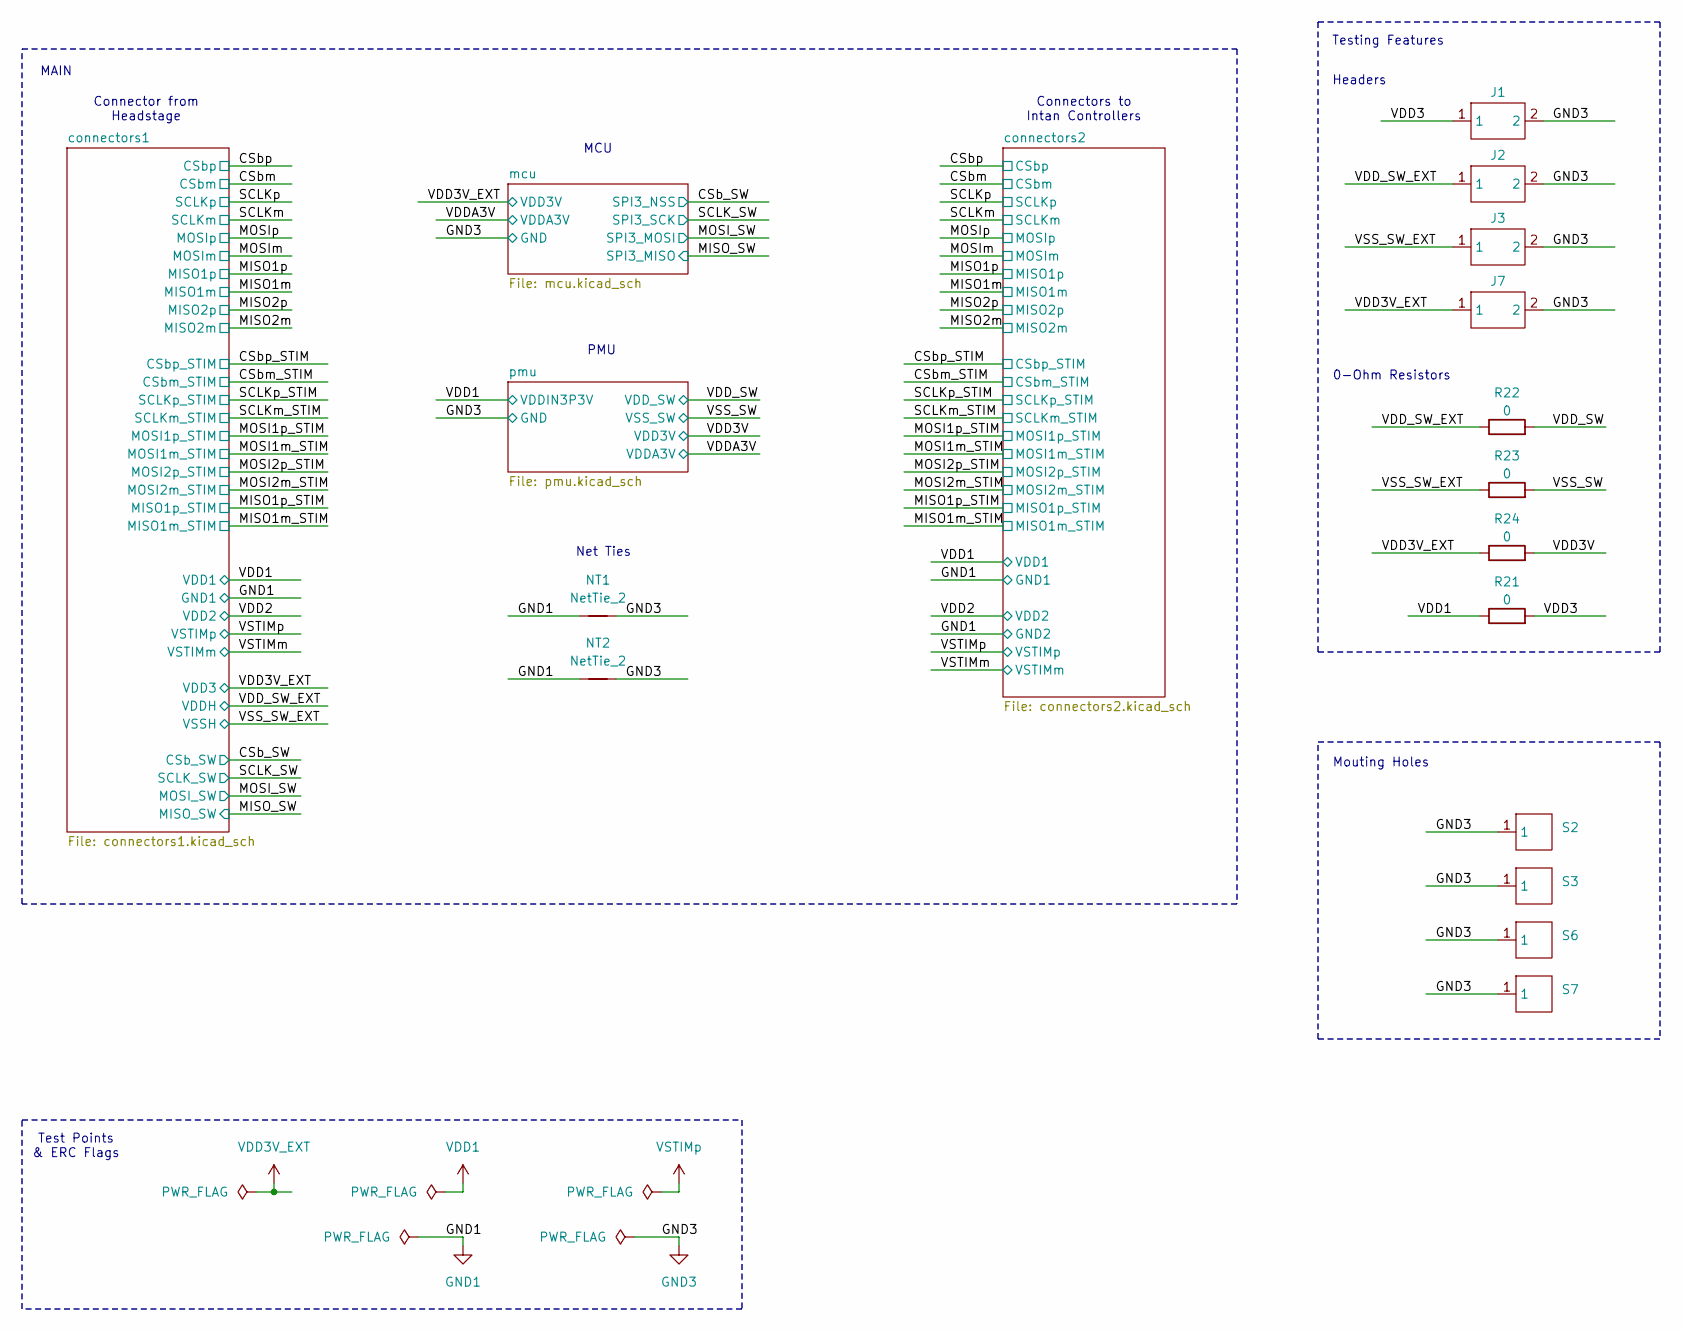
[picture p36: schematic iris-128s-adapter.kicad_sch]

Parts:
J1, J2, J3, J7: TLW-102-06-G-S; MPN TLW-102-06-G-S
NT1, NT2: NetTie_2; NetTie-2_SMD_Pad0.5mm; MPN None
R21, R22, R23, R24: 0; R_0402_1005Metric; MPN RC0402JR-070RL
S2, S3, S6, S7: MOUNTING_HOLE-PAD-0.1IN; MPN None

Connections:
/VDD3: J1.1, R21.2
/VDD3V: R24.2; also elsewhere on the board
/VDD_SW: R22.2; also elsewhere on the board
/VDD_SW_EXT: J2.1, R22.1; also elsewhere on the board
/VSS_SW: R23.2; also elsewhere on the board
/VSS_SW_EXT: J3.1, R23.1; also elsewhere on the board
GND1: NT1.1, NT2.1; also elsewhere on the board
GND3: J1.2, J2.2, J3.2, J7.2, NT1.2, NT2.2, S2.1, S3.1, S6.1, S7.1; also elsewhere on the board
VDD1: R21.1; also elsewhere on the board
VDD3V_EXT: J7.1, R24.1; also elsewhere on the board

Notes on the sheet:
Net Ties
MAIN
Connector from Headstage
Test Points & ERC Flags
Mouting Holes
Headers
MCU
PMU
0-Ohm Resistors
Connectors to Intan Controllers
Testing Features


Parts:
S5: OMNETICS-A79024-001; MPN A79024-001

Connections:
/CSb_SW: S5.T14; also elsewhere on the board
/CSbm: S5.B4; also elsewhere on the board
/CSbm_STIM: S5.B8; also elsewhere on the board
/CSbp: S5.B5; also elsewhere on the board
/CSbp_STIM: S5.B9; also elsewhere on the board
/MISO1m: S5.T4; also elsewhere on the board
/MISO1m_STIM: S5.B12; also elsewhere on the board
/MISO1p: S5.T5; also elsewhere on the board
/MISO1p_STIM: S5.B13; also elsewhere on the board
/MISO2m: S5.T6; also elsewhere on the board
/MISO2p: S5.T7; also elsewhere on the board
/MISO_SW: S5.T15; also elsewhere on the board
/MOSI1m_STIM: S5.T10; also elsewhere on the board
/MOSI1p_STIM: S5.T11; also elsewhere on the board
/MOSI2m_STIM: S5.T12; also elsewhere on the board
/MOSI2p_STIM: S5.T13; also elsewhere on the board
/MOSI_SW: S5.B15; also elsewhere on the board
/MOSIm: S5.T8; also elsewhere on the board
/MOSIp: S5.T9; also elsewhere on the board
/SCLK_SW: S5.B14; also elsewhere on the board
/SCLKm: S5.B6; also elsewhere on the board
/SCLKm_STIM: S5.B10; also elsewhere on the board
/SCLKp: S5.B7; also elsewhere on the board
/SCLKp_STIM: S5.B11; also elsewhere on the board
/VDD2: S5.B1; also elsewhere on the board
/VDD_SW_EXT: S5.T17; also elsewhere on the board
/VSS_SW_EXT: S5.T18; also elsewhere on the board
/VSTIMm: S5.T1; also elsewhere on the board
GND1: S5.B3, S5.B16, S5.T3, S5.T16; also elsewhere on the board
VDD1: S5.B2; also elsewhere on the board
VDD3V_EXT: S5.B17, S5.B18; also elsewhere on the board
VSTIMp: S5.T2; also elsewhere on the board

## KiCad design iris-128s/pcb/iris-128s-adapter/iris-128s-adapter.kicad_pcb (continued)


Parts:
C1: 4.7u; C_0402_1005Metric; MPN KGM05CR51C475MH
C2: 1u; C_0201_0603Metric; MPN GRM033R61C105ME15D
C3, C4, C6, C24: 100n; C_0201_0603Metric; MPN C0603X5R1C104K030BC
C5: 10n; C_0201_0603Metric; MPN GRM033R61C103KA12D
C22, C23: 2p; C_0201_0603Metric; MPN GJM0335C1E2R0WB01D
D3: ROHM-LED-0603; MPN CSL1901UW1
J4: SMD-ARM10-10_2x5_P0.05in; MPN FTSH-105-01-L-DV-K
J5: SLW-110-01-G-D; MPN SLW-110-01-G-D
J6: BOURNES-PUSHBUTTON-7914G-1-000; MPN 7914G-1-000
R1: 0; R_0201_0603Metric; MPN RC0201FR-070RL
R3, R4: 4.7k; R_0201_0603Metric; MPN RC0201FR-074K7L
R5, R6, R7, R8: 0; R_0402_1005Metric; MPN RC0402JR-070RL
R19: 402; R_0402_1005Metric; MPN RCS0402402RFKED
U1: UFQFPN-32-1EP_5x5mm_P0.5mm_EP3.6x3.6mm; MPN STM32U083KCU6
X1: CRYSTAL-ECS-ECX-1210B-32KHZ; MPN ECS-.327-6-1210B-N-TR

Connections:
/CSb_SW: R8.2; also elsewhere on the board
/MISO_SW: R6.2; also elsewhere on the board
/MOSI_SW: R5.2; also elsewhere on the board
/SCLK_SW: R7.2; also elsewhere on the board
/VDDA3V: C2.1, C4.1, C5.1, U1.5 (VDDA/VREF+); also elsewhere on the board
/mcu/NRST: C6.1, J4.10, J6.2A, J6.2B, U1.4 (PF2-NRST)
/mcu/PA0: J5.1, U1.6 (PA0-CK_IN)
/mcu/PA1: J5.2, U1.7 (PA1)
/mcu/PA2: J5.3, U1.8 (PA2)
/mcu/PA3: J5.4, U1.9 (PA3)
/mcu/PA4: J5.5, U1.10 (PA4)
/mcu/PA5: J5.6, U1.11 (PA5)
/mcu/PA6: J5.7, U1.12 (PA6)
/mcu/PA7: J5.8, U1.13 (PA7)
/mcu/PA8: R19.2, U1.18 (PA8)
/mcu/PA9: J5.11, R4.2, U1.19 (PA9)
/mcu/PA10: J5.12, R3.2, U1.20 (PA10)
/mcu/PA11: J5.13, U1.21 (PA11[PA9])
/mcu/PA12: J5.14, U1.22 (PA12[PA10])
/mcu/PB0: J5.15, U1.14 (PB0)
/mcu/PB1: J5.16, U1.15 (PB1)
/mcu/PB6: J5.17, U1.29 (PB6)
/mcu/PB7: J5.18, U1.30 (PB7)
/mcu/SWCLK: J4.4, U1.24 (PA14)
/mcu/SWDIO: J4.2, U1.23 (PA13)
GND3: C1.2, C2.2, C3.2, C4.2, C5.2, C6.2, C22.2, C23.2, C24.2, J4.3, J4.5, J4.9, J5.9, J5.19, J6.1A, J6.1B, R1.2, U1.16 (VSS1), U1.32 (VSS2), U1.33 (Exposed_Pad), X1.2 (GND), X1.4 (NC); also elsewhere on the board
unnamed: D3.2, R19.1
unnamed: R8.1, U1.25 (PA15)
unnamed: R7.1, U1.26 (PB3)
unnamed: R6.1, U1.27 (PB4)
unnamed: R5.1, U1.28 (PB5)
unnamed: C22.1, U1.2 (PC14-OSC32_IN), X1.1 (IN/OUT)
unnamed: C23.1, U1.3 (PC15-OSC32_OUT), X1.3 (OUT/IN)
unnamed: R1.1, U1.31 (PF3-BOOT0)
VDD3V_EXT: C1.1, C3.1, C24.1, D3.1, J4.1, J5.10, J5.20, R3.1, R4.1, U1.1 (VDD1), U1.17 (VDD2); also elsewhere on the board

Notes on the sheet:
I2C Pull-ups
SPI1_NSS SPI1_SCK SPI1_MISO SPI1_MOSI
CSL1901UW1 VF=1.8V @IF=2mA
Expansion Connector (0.1in Header)
Programming Connector (SWD)
Bypass Capacitors


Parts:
S1: OMNETICS_PZN-12-AA; MPN A79623-001
S4: OMNETICS_PZN-16-AA; MPN A79633-001

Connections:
/CSbm: S1.B1 (CSbm); also elsewhere on the board
/CSbm_STIM: S4.B7 (CSbm); also elsewhere on the board
/CSbp: S1.T1 (CSbp); also elsewhere on the board
/CSbp_STIM: S4.B6 (CSbp); also elsewhere on the board
/MISO1m: S1.B4 (MISO1m); also elsewhere on the board
/MISO1m_STIM: S4.T6 (MISO1m); also elsewhere on the board
/MISO1p: S1.T4 (MISO1p); also elsewhere on the board
/MISO1p_STIM: S4.T7 (MISO1p); also elsewhere on the board
/MISO2m: S1.B5 (MISO2m); also elsewhere on the board
/MISO2p: S1.T5 (MISO2p); also elsewhere on the board
/MOSI1m_STIM: S4.T4 (MOSI1m); also elsewhere on the board
/MOSI1p_STIM: S4.T5 (MOSI1p); also elsewhere on the board
/MOSI2m_STIM: S4.B5 (MOSI2m); also elsewhere on the board
/MOSI2p_STIM: S4.B4 (MOSI2p); also elsewhere on the board
/MOSIm: S1.B3 (MOSIm); also elsewhere on the board
/MOSIp: S1.T3 (MOSIp); also elsewhere on the board
/SCLKm: S1.B2 (SCLKm); also elsewhere on the board
/SCLKm_STIM: S4.T2 (SCLKm); also elsewhere on the board
/SCLKp: S1.T2 (SCLKp); also elsewhere on the board
/SCLKp_STIM: S4.T3 (SCLKp); also elsewhere on the board
/VDD2: S4.T8 (VDD); also elsewhere on the board
/VSTIMm: S4.T1 (VSTIMm); also elsewhere on the board
GND1: S1.B6 (GND), S4.B8 (GND); also elsewhere on the board
VDD1: S1.T6 (VDD); also elsewhere on the board
VSTIMp: S4.B1 (VSTIMp); also elsewhere on the board


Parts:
C7, C12, C13: 10u; C_0603_1608Metric; MPN GRM188R61E106KA73D
C8, C10: 33n; C_0201_0603Metric; MPN GRM033R61C333KE84D
C9, C11, C16, C18, C19: 1u; C_0201_0603Metric; MPN GRM033R61C105ME15D
C14, C15, C20, C21: 2.2u; C_0201_0603Metric; MPN GRM035R61C225ME01D
C17: 1n; C_0201_0603Metric; MPN GRM033R61E102KA01J
D1, D2: X3-WLB1006-2; MPN SDM05U20CSP-7
D4: OSRAM-LED-0603; MPN LGQ396
L1: 3.3u; SMD-0808; MPN XFL2006-332MEC
L2: 4.7u; SMD-0808; MPN XFL2006-472MEC
R9: 4.87k; R_0201_0603Metric; MPN RC0201FR-074K87L
R10: 7.5k; R_0201_0603Metric; MPN RC0201FR-077K5L
R11: 1.15M; R_0201_0603Metric; MPN CRCW02011M15FNED
R12, R13: 100k; R_0201_0603Metric; MPN RC0201FR-07100KL
R14: 1.33M; R_0201_0603Metric; MPN CRCW02011M33FNED
R15: 8.06k; R_0201_0603Metric; MPN RC0201FR-078K06L
R16, R18: 10k; R_0201_0603Metric; MPN RC0201FR-0710KL
R17: 64.9k; R_0201_0603Metric; MPN RC0201FR-0764K9L
R20: 499; R_0402_1005Metric; MPN RCS0402499RFKED
U2: LFCSP-20-1EP_4mmx4mm_P0.5mm_EP2.6mm; MPN ADP5070ACPZ-R7
U3: LFCSP-6-1EP_2mmx2mm_P0.65mm_EP1.6mmx1mm; MPN ADP7142ACPZN5.0-R7
U4: LFCSP-6-1EP_2mmx2mm_P0.65mm_EP1.6mmx1mm; MPN ADP7182ACPZN-R7
U5: WSON-6_1.5mmx1.5mm_P0.5mm; MPN TLV7113030DDSER

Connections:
/VDD3V: C19.1, U5.6 (OUT1); also elsewhere on the board
/VDDA3V: C18.1, U5.5 (OUT2); also elsewhere on the board
/VDD_SW: C20.1, R15.1, U3.1 (VOUT); also elsewhere on the board
/VSS_SW: C21.1, R17.1, U4.1 (VOUT); also elsewhere on the board
/pmu/VDDH: C12.1, C14.1, D1.1, R11.2, U3.4 (EN), U3.6 (VIN)
/pmu/VSSH: C13.2, C15.1, D2.2, R14.2, U4.3 (EN), U4.6 (VIN), U4.7 (EP)
GND3: C7.2, C8.1, C9.1, C10.1, C11.2, C12.2, C13.1, C14.2, C15.2, C16.2, C17.2, C18.2, C19.2, C20.2, C21.2, L2.1, R12.2, R16.2, R18.2, R20.1, U2.13 (AGND), U2.19 (PGND), U2.21 (EP), U3.3 (GND), U3.7 (EP), U4.5 (GND), U5.4 (GND); also elsewhere on the board
unnamed: C8.2, R9.1
unnamed: C10.2, R10.1
unnamed: D4.2, R20.2
unnamed: R9.2, U2.6 (COMP1)
unnamed: R10.2, U2.10 (COMP2)
unnamed: R11.1, R12.1, U2.5 (FB1)
unnamed: R13.2, R14.1, U2.11 (FB2)
unnamed: L1.2, U2.1 (INBK)
unnamed: C9.2, U2.2 (SYNC/FREQ), U2.3 (SEQ), U2.14 (VREG)
unnamed: D1.2, L1.1, U2.20 (SW1)
unnamed: D2.1, L2.2, U2.18 (SW2)
unnamed: C11.1, R13.1, U2.12 (VREF)
unnamed: R15.2, R16.1, U3.2 (SENSE/ADJ)
unnamed: C17.1, U3.5 (SS)
unnamed: R17.2, R18.1, U4.2 (ADJ)
VDD1: C7.1, C16.1, D4.1, U2.7 (EN1), U2.9 (EN2), U2.15 (PVIN1), U2.16 (PVINSYS), U2.17 (PVIN2), U5.1 (EN1), U5.2 (IN), U5.3 (EN2); also elsewhere on the board

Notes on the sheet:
Regulators
LGQ396 VF=1.9V @IF=2mA
-9V
DC-DC Converter
-10V
Adjustable Output ADP7182ACPZN-R7
ADP5070ACPZ-R7
Dual Outputs TLV7113030(U/D)WWW(R/T)
+9V
+5V Standard Output ADP7142ACPZN5.0-R7
SYNC/FREQ=VREG: 2.4MHz SLEW=OPEN: Fastest Slew Rate (best efficiency) SEQ=VREG: Simultaneous VDDH/VSSH startup SS=OPEN: Fastest soft start time.
TLV7113030DDSER
+10V
VOUT=5V(1+R15/R16)
-VOUT=-1.22V(1+R17/R18)



Board: 4 copper layers, 50.0 x 40.0 mm, 75 parts (39 on the bottom side), 83 nets.

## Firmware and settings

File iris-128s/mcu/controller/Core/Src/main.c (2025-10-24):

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
/* Includes ------------------------------------------------------------------*/
#include "main.h"


SPI_HandleTypeDef hspi3;

/* USER CODE BEGIN PV */

/* Buffer used for transmission */
// Command to enter daisy-chain mode
const char cmd0 = (char)(0b00100101);
const char cmd1 = (char)(0b00000000);

/* Switches states: swX=[7..0] */
// Default values
const char sw1 = (char)(0b00000000);
const char sw2 = (char)(0b00000000);
const char sw3 = (char)(0b11111111);
const char sw4 = (char)(0b11111111);
const char sw5 = (char)(0b11111111);
const char sw6 = (char)(0b11111111);
const char sw7 = (char)(0b00000000);
const char sw8 = (char)(0b00000000);

/* Buffer used for transmission */
uint8_t aTxBuffer[20];

#define BUFFERSIZECMD 2
#define BUFFERSIZEDATA 8

/* Buffer used for reception */
uint8_t aRxBuffer[20];

/* USER CODE END PV */

void SystemClock_Config(void);
static void MX_GPIO_Init(void);
static void MX_SPI3_Init(void);
/* USER CODE BEGIN PFP */

void SPI_TX(SPI_HandleTypeDef hspi, uint8_t *pData, uint16_t Size);

/* USER CODE END PFP */

/**
  * @brief  The application entry point.
  * @retval int
  */
int main(void)
{

  /* MCU Configuration--------------------------------------------------------*/

  /* Reset of all peripherals, Initializes the Flash interface and the Systick. */
  HAL_Init();

  /* Configure the system clock */
  SystemClock_Config();

  /* Initialize all configured peripherals */
  MX_GPIO_Init();
  MX_SPI3_Init();

  /* USER CODE BEGIN 2 */

  /* Turn On LED*/
  HAL_GPIO_WritePin(GPIOA, GPIO_PIN_8, GPIO_PIN_RESET);

  /* Set NSS (CSb) to High */
  HAL_GPIO_WritePin(GPIOA, GPIO_PIN_15, GPIO_PIN_SET);

  HAL_Delay(1000);

  // Daisy-Chain Command
  // -------------------------------------------------------------------------------
  // TX order (First to Last): cmd0,cmd1
  aTxBuffer[0] = cmd0;
  aTxBuffer[1] = cmd1;

  SPI_TX(hspi3, aTxBuffer, BUFFERSIZECMD);

  // Switch-Data Command
  // -------------------------------------------------------------------------------
  // Switches states: swX=[7..0]
  aTxBuffer[0] = sw1;
  aTxBuffer[1] = sw2;
  aTxBuffer[2] = sw3;
  aTxBuffer[3] = sw4;
  aTxBuffer[4] = sw5;
  aTxBuffer[5] = sw6;
  aTxBuffer[6] = sw7;
  aTxBuffer[7] = sw8;

  SPI_TX(hspi3, aTxBuffer, BUFFERSIZEDATA);

  /* USER CODE END 2 */

  /* Infinite loop */
  /* USER CODE BEGIN WHILE */
  while (1)
  {
    /* USER CODE END WHILE */

    /* USER CODE BEGIN 3 */
		/* Toggle LED every half-second*/
		HAL_Delay(500);
		HAL_GPIO_TogglePin(GPIOA, GPIO_PIN_8);

		/* Toggle LED every half-second*/
		HAL_Delay(500);
		HAL_GPIO_TogglePin(GPIOA, GPIO_PIN_8);

  }
  /* USER CODE END 3 */
}

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
/* USER CODE BEGIN 4 */
void SPI_TX(SPI_HandleTypeDef hspi, uint8_t *pData, uint16_t Size)
{
	/*##-1- Start the Full Duplex Communication process ########################*/
	/* While the SPI in Transmit process, user can transmit data through "aTxBuffer" buffer */
	/* Timeout is set to 5S */

	/* Set NSS (CSb) to Low */
	HAL_GPIO_WritePin(GPIOA, GPIO_PIN_15, GPIO_PIN_RESET);

	switch (HAL_SPI_Transmit(&hspi, pData, Size, 5000))
	{
	case HAL_OK:
		/* Communication is completed ___________________________________________ */
		/* Set NSS (CSb) to High */
		HAL_GPIO_WritePin(GPIOA, GPIO_PIN_15, GPIO_PIN_SET);

		break;

	case HAL_TIMEOUT:
		/* An Error Occur ______________________________________________________ */
	case HAL_ERROR:
		/* Call Timeout Handler */
		Error_Handler();
		break;
	default:
		break;
	}
}
/* USER CODE END 4 */
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


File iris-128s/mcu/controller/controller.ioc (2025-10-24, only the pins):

Mcu.UserName=STM32U083KCUx
PA15.Signal=GPIO_Output
PA8.Signal=GPIO_Output
PB3.Signal=SPI3_SCK
PB4.Signal=SPI3_MISO
PB5.Signal=SPI3_MOSI
PC14-OSC32_IN.Signal=RCC_OSC32_IN
PC15-OSC32_OUT.Signal=RCC_OSC32_OUT

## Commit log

2025-10-24 update with pcb and mcu files.
    [analog_muxes_switches.kicad_sch, connectors.kicad_sch, connectors1.kicad_sch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]
2025-10-24 Added iris-128b.
    [chip.kicad_sch, electrodes128.kicad_sch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]
2025-10-25 simplified folder structure table and moved file type table to device-folder.
2025-10-29 adapter board files
    [iris-128b-adapter.kicad_pcb, iris-128b-adapter.kicad_sch, iris-128b.kicad_pcb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]
2025-10-29 license update, readme, and manufacturing files
    [iris-128b-adapter-B_Cu.gbr, iris-128b-adapter-B_Mask.gbr, iris-128b-adapter-B_Paste.gbr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]
2025-11-05 documentation folder
    [iris-128b-adapter-bom.xlsx]

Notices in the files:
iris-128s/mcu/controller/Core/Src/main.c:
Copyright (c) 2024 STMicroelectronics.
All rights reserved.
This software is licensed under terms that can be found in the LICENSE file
